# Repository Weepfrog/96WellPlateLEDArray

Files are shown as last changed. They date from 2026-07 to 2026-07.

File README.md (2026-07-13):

# 12×8 High-Power 660nm LED Array

A 96-LED (12 across × 8 down, 9 mm pitch) deep-red 660 nm panel with **per-LED
dimming** and **per-LED temperature sensing**, driven by an ESP32 DevKitC.
Designed for JLCPCB fabrication + assembly; all parts chosen from the
JLCPCB/LCSC library (stock verified 2026-07-13).

## System overview

```
24V 4-6A brick ──► CONTROL BOARD ══ 4× 50-way + 1× 20-way IDC ribbon ══► LED BOARD
                   96× PT4115 buck CC        192 anode/cathode lines        96× 660nm 3535 LED
                   6× PCA9685 PWM (I2C)      + analog/logic lines           96× 10k NTC
                   XL1509 5V rail                                           6× CD74HC4067 mux
                   ESP32 DevKitC socket                                     flat back → heatsink
                   3 buttons + status LEDs
```

- **~50 W** total at full drive (≈0.5 W per LED @ 256 mA, huge margin on 3 W-rated LEDs)
- Per-LED PWM: one PT4115 buck constant-current channel per LED, DIM pins on six
  PCA9685 16-channel I2C PWM expanders (run PWM at ~244 Hz → ~10-11 usable bits)
- Per-LED temperature: one 0603 NTC beside each LED, multiplexed 16:1 onto six
  ESP32 ADC1 inputs
- LED board is 4-layer with thermal-via farms; back face is bare copper for a
  bolt-on heatsink (use an insulating thermal pad)

## Repository layout

| Path | What |
|---|---|
| `12x8 Led Array 9mm pitch/` | **LED board** KiCad project (96 LEDs + NTCs + muxes) |
| `control-board/` | **Control board** KiCad project (drivers, PWM, ESP32, UI) |
| `libraries/` | `jlc_parts` symbol/footprint/3D library (converted from EasyEDA, JLCPCB-exact pads) |
| `scripts/design_data.py` | **Single source of truth**: every part, position, and net |
| `scripts/gen_schematics.py` | Regenerates both `.kicad_sch` (parts placed, you wire per CONNECTIONS.md) |
| `scripts/gen_pcbs.py` | Regenerates both `.kicad_pcb` (footprints pre-placed) |
| `reference/datasheets/` | Datasheets for key parts |
| `production/` | JLCPCB BOM + CPL exports |
| `CONNECTIONS.md` | **Your wiring guide** — every net, pin by pin |

## Workflow

1. **Schematics are hierarchical and fully wired**: each board is a root
   sheet + one sub-sheet (`well.kicad_sch` / `channel.kicad_sch`)
   instantiated 96×, with references matching `CONNECTIONS.md` (LED1-96,
   U1-96, …). Verified automatically: KiCad's exported netlist matches the
   intended netlist in `design_data.py` net-for-net; ERC is clean (3 benign
   library-mismatch warnings on the control board). Review, then move to
   layout.
2. Open the PCB — footprints are pre-placed (LED grid at exact 9.0 mm
   pitch; placement still draft). Run **Tools → Update PCB from Schematic
   (F8)**, then route.
3. Regenerating: `python scripts/gen_schematics_hier.py`, then
   `scripts/gen_pcbs.py` with KiCad's Python (see script headers), then
   `python scripts/gen_connections.py`. Verify with
   `scripts/verify_netlist.py` (see header). **Regeneration overwrites the
   sch/pcb files** — don't rerun after manual edits unless you want a reset.

## Key design rules (don't skip)

- **LED polarity:** pad 1 = anode (marked `+` on silk), pad 2 = cathode,
  pad 3 = center thermal pad — **tie pad 3 to pad 2 (cathode)** per Hongli's
  datasheet. Each LED's thermal island is at its own cathode potential, so the
  heatsink must be electrically isolated (thermal pad, not bare paste).
- **PT4115 DIM floats high** = full brightness. Every DIM has a 100k pulldown
  so the panel boots dark. Keep them.
- **One reflow only** for the LEDs (datasheet) — LED board is single-side
  assembly, which satisfies this. Don't hot-air rework casually.
- 24 V power enters each board via its own screw terminal — **do not route
  LED supply current through the IDC ribbons** (they carry per-channel
  anode/cathode pairs and logic only).
- IDC headers and ESP32 sockets are through-hole: hand-solder them (cheaper
  than JLCPCB THT assembly).

## Swapping LED wavelengths

The design is wavelength-agnostic on purpose:

- The 3535 3-pad footprint is the industry-standard pattern (Cree XP
  compatible). 730 nm far-red, 850/940 nm IR, blue, and UV parts from Hongli,
  Silverlight, JNJ and others drop straight in.
- The PT4115 buck **does not care about forward voltage** — anything from
  ~1.5 V (IR) to ~3.4 V (blue/UV) runs at the same regulated current with zero
  component changes.
- Current is set only by the 0.39 Ω sense resistor (256 mA). For a lower-rated
  LED, change R1–R96 on the control board: `I = 0.1 V / Rs`.
- Checklist when swapping: 3535 package with center pad, anode on pad 1 /
  matching polarity, continuous current rating ≥ 300 mA, note the part's own
  reflow limits.
- Mixed arrays are fine too (e.g. 660 nm + 730 nm checkerboard) since every
  channel is independent.

## Firmware map (ESP32 DevKitC-38)

| GPIO | Function |
|---|---|
| 21 / 22 | I2C SDA / SCL → PCA9685 ×6 (0x40–0x45), optional ADS1115 (0x48) |
| 16 / 17 / 18 / 19 | Mux address S0–S3 (shared, all six muxes) |
| 32, 33, 34, 35, 36, 39 | ADC1 inputs ← NTC_SIG1–6 (mux outputs) |
| 25 | Fan PWM (low-side AO3400A) |
| 4 / 13 | Status LED (blue) / Fault LED (red) |
| 14 / 27 / 26 | Buttons MODE / UP / DOWN (to GND, internal pull-ups) |

NTC conversion: 10k NTC (B=3434 K) high side, 10k 1% low side, ratiometric to
3.3 V. Scan all 96 via mux (settle ≥200 µs after address change). Derate any
channel whose pad temperature approaches 85 °C (Hongli's recommended limit).

## Safety

50 W of 660 nm in a 10 cm square is extremely bright — never look at the
array at power, ramp brightness in firmware, and treat the NTC thermal
shutdown as a backstop, not a substitute for the heatsink.

## Status

- [x] Architecture + parts selection (all JLCPCB-stocked, C-numbers in BOM)
- [x] Schematics generated, parts placed with library-verified pinouts
- [ ] PCBs with pre-placed footprints
- [ ] CONNECTIONS.md wiring guide
- [ ] JLCPCB BOM/CPL exports
- [ ] User wiring + routing
- [ ] Order + bring-up

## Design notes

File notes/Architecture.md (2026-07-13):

---
tags: [96-well-led-array, hardware]
---

# Architecture

```
24V 4-6A brick ─┬─► CONTROL BOARD (170×190mm, 2-layer)
                │     96× PT4115 buck CC channel (256mA, one per well)
                │     6× PCA9685 16-ch I2C PWM → per-well dimming
                │     XL1509-5.0 → 5V rail → ESP32 DevKitC (socketed)
                │     3 buttons + 3 status LEDs + fan switch
                │
                │  4× 50-way IDC ribbon (192 anode/cathode lines)
                │  1× 20-way IDC ribbon (6 analog + 4 addr + 3V3 + GND)
                │
                └─► LED BOARD (140×120mm, 4-layer, flat back → heatsink)
                      96× 660nm 3535 LED at exact 9.0mm SBS pitch
                      96× 10k NTC (one beside each LED)
                      6× CD74HC4067 16:1 mux
```

## Why this shape

- **Per-well dimming at 256 mA** rules out matrix scanning (can't sustain
  power) and display-driver ICs (≤90 mA). One tiny hysteretic buck per LED is
  the cheapest correct answer (~$0.19/channel). See [[Design Decisions]].
- The PT4115 floats its LED between the sense resistor and the inductor, so
  **each well needs its own anode AND cathode line** — hence 192 ribbon lines.
  Each channel's pair sits on adjacent IDC pins to minimize loop area.
- Drivers live on the control board so the LED board's back face is a flat,
  unbroken thermal surface and the NTC analog lines stay away from switching
  noise.
- 96 NTC signals reduce to 10 ribbon lines via the six on-board muxes.

## Channel numbering

`n = (row-1)*12 + col`, rows top→bottom 1-8, cols left→right 1-12, viewed
from the LED side. CH1 = A1 corner well, CH96 = H12. Same numbering on both
boards, in [[../CONNECTIONS|CONNECTIONS]], and in firmware.

## Thermal path

LED thermal pad (tied to its cathode) → 5-via farm → inner + back copper →
insulating thermal pad → heatsink. Per-well NTC lets firmware derate any hot
well; Hongli's limit is 85 °C at the cathode pad ([[Bring-Up Checklist]]).
Heatsink must be electrically isolated because the thermal islands carry
cathode potential.

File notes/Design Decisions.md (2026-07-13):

---
tags: [96-well-led-array, decisions]
---

# Design Decisions

Decisions confirmed 2026-07-13 (planning session): **~50 W** total power ·
**24 V** brick · **per-LED control** · **two boards**.

## Topology: one buck per LED

Considered and rejected:
- **Matrix scanning** — 1/8 duty needs 8× peak current; LEDs can't sustain it,
  and average power collapses.
- **Multichannel display drivers** (TLC59xx, MBI…) — top out at ~60-90 mA/ch;
  we need 256 mA.
- **String + shunt-switch (TPS92662 matrix manager)** — elegant but pricey,
  automotive parts thin at LCSC.
- **Linear per-channel from a low rail** — a 24 V→3 V/34 A converter plus 40 W
  of linear dissipation; awful.

**Chosen:** PT4115 hysteretic buck per channel from 24 V. Confirmed by
datasheet math: single 2.1 V LED from 24 V → ~9 % duty, fsw ≈ 630 kHz with
47 µH — inside the 1 MHz limit, no minimum-on-time problem.

## LED: Hongli HL-C3535F15R3GA-ZW (C5445086)

- No 660 nm LED exists in JLCPCB's *Basic* library; nothing viable ≥0.5 W in
  2835/3030 was in stock → 3535 it is.
- 3 W-rated part run at 0.5 W → big lifetime/thermal margin.
- Pad 1 = anode (`+` silk), pad 2 = cathode, pad 3 = thermal → **tie pad 3 to
  pad 2** per datasheet recommendation (safe whether or not the pad is
  internally bonded to the cathode).
- **One reflow only** — LED board is single-side assembly. Avoid hot-air rework.

## LED swapability

Requirement: swap wavelengths without redesign.
- 3535 3-pad is the industry-standard (XP-style) footprint: 730 nm far-red,
  850/940 nm IR, blue, UV drop in.
- PT4115 buck is Vf-agnostic (~1.5–3.4 V all fine) — zero component changes.
- Current set only by Rs: `I = 0.1 V / 0.39 Ω = 256 mA`; change R1-R96 on the
  control board for lower-rated LEDs.
- Mixed-wavelength (e.g. 660/730 checkerboard) works since channels are
  independent.

## Dimming: PCA9685 at ~244 Hz

PCA9685's 12-bit PWM at max 1526 Hz has 160 ns LSBs — far below the PT4115
DIM response (~tens of µs). At 244 Hz prescale, 1 LSB ≈ 1 µs → **~10-11 usable
bits**, monotonic. Full-panel update over 400 kHz I2C ≈ 90 Hz.
PCA9685 is NXP-only at LCSC (~$2, the priciest BOM line); AW9523B is the
8-bit fallback if it goes out of stock.

## Temperature sensing

10k NTC (B=3434) + 10k 1% divider from 3.3 V, ratiometric into the ESP32 ADC
(nonlinearity mostly cancels; absolute accuracy ±2 °C is plenty for derating).
Six CD74HC4067 on the LED board; ADS1115 footprint on the control board is
DNP insurance if the internal ADC disappoints.

## Boot safety

PT4115 DIM **floating = 100 % on**. Defenses: PCA9685 outputs are LOW at
reset, /OE hard-tied to GND, and a 100k pulldown on every DIM line. The panel
cannot boot bright.

## Interconnect

2.54 mm shrouded IDC (2.5-3 A/pin vs 256 mA needed), keyed against reversal.
24 V never crosses the ribbons — it enters only at the control board screw
terminal/barrel jack. Ribbon spare pins carry GND.

## Related

[[Architecture]] · [[Parts and BOM]] · [[../CONNECTIONS|CONNECTIONS]]

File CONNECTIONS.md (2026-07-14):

# CONNECTIONS.md — complete wiring reference

Generated from `scripts/design_data.py`. The hierarchical schematics are **already wired to match this document** (verified: KiCad's exported netlist matches every net below exactly, ERC clean). Use this as the review checklist and as the reference during PCB routing, firmware bring-up, and debugging.

**Channel numbering:** `n = (row-1)*12 + col`, rows top→bottom 1-8, columns left→right 1-12 looking at the LED side. CH1 = top-left well, CH96 = bottom-right.

## ESP32 DevKitC-38 socket map (control board J10/J11)

J10 = left socket row, J11 = right socket row, **pin 1 of both = the 3V3/GND end** (opposite the USB connector).

| J10 pin | DevKit pin | Connect to | | J11 pin | DevKit pin | Connect to |
|---|---|---|---|---|---|---|
| 1 | 3V3 | +3.3V | | 1 | GND | GND |
| 2 | EN | — | | 2 | GPIO23 | — |
| 3 | GPIO36/VP | NTC_SIG5 | | 3 | GPIO22 | I2C_SCL |
| 4 | GPIO39/VN | NTC_SIG6 | | 4 | GPIO1/TX0 | — |
| 5 | GPIO34 | NTC_SIG3 | | 5 | GPIO3/RX0 | — |
| 6 | GPIO35 | NTC_SIG4 | | 6 | GPIO21 | I2C_SDA |
| 7 | GPIO32 | NTC_SIG1 | | 7 | GND | GND |
| 8 | GPIO33 | NTC_SIG2 | | 8 | GPIO19 | MUX_A3 |
| 9 | GPIO25 | FAN_PWM | | 9 | GPIO18 | MUX_A2 |
| 10 | GPIO26 | BTN_DOWN | | 10 | GPIO5 | — |
| 11 | GPIO27 | BTN_UP | | 11 | GPIO17 | MUX_A1 |
| 12 | GPIO14 | BTN_MODE | | 12 | GPIO16 | MUX_A0 |
| 13 | GPIO12 | — | | 13 | GPIO4 | LED_STATUS |
| 14 | GND | GND | | 14 | GPIO0 | — |
| 15 | GPIO13 | LED_FAULT | | 15 | GPIO2 | — |
| 16 | GPIO9/D2 | — | | 16 | GPIO15 | — |
| 17 | GPIO10/D3 | — | | 17 | GPIO8/D1 | — |
| 18 | GPIO11/CMD | — | | 18 | GPIO7/D0 | — |
| 19 | 5V | +5V | | 19 | GPIO6/CLK | — |

GPIO summary: **GPIO21** = I2C SDA (PCA9685 x6, ADS1115 opt.); **GPIO22** = I2C SCL; **GPIO16** = MUX_A0; **GPIO17** = MUX_A1; **GPIO18** = MUX_A2; **GPIO19** = MUX_A3; **GPIO32** = NTC_SIG1 (ADC1_CH4); **GPIO33** = NTC_SIG2 (ADC1_CH5); **GPIO34** = NTC_SIG3 (ADC1_CH6); **GPIO35** = NTC_SIG4 (ADC1_CH7); **GPIO36/VP** = NTC_SIG5 (ADC1_CH0); **GPIO39/VN** = NTC_SIG6 (ADC1_CH3); **GPIO25** = FAN_PWM (Q1 gate via R201); **GPIO4** = STATUS LED2 (blue); **GPIO13** = FAULT LED3 (red); **GPIO14** = SW1 MODE (to GND, internal pull-up); **GPIO27** = SW2 UP (to GND, internal pull-up); **GPIO26** = SW3 DOWN (to GND, internal pull-up)

## Logical channel map (well ↔ channel ↔ driver ↔ PWM)

The driver serving a well is **not** the same index — each board's ribbon pinout was optimized independently to minimize crossings, and the cable wires them together slot-for-slot. Firmware addresses a well's brightness through the PCA output in this table, and reads its temperature through the mux input. **This is the mapping to hard-code.**

| CH | Well (grid) | Ribbon | Driver | PWM (PCA.out) | NTC (mux.in) |
|---|---|---|---|---|---|
| 1 | LED37 (r4c1) | J1 p1/2 | U10 | U105.LED2 | U3.I5 |
| 2 | LED38 (r4c2) | J1 p3/4 | U11 | U105.LED1 | U3.I10 |
| 3 | LED39 (r4c3) | J1 p5/6 | U12 | U105.LED0 | U3.I4 |
| 4 | LED40 (r4c4) | J1 p7/8 | U21 | U105.LED6 | U3.I11 |
| 5 | LED25 (r3c1) | J1 p9/10 | U22 | U105.LED5 | U2.I3 |
| 6 | LED41 (r4c5) | J1 p11/12 | U23 | U105.LED4 | U3.I3 |
| 7 | LED26 (r3c2) | J1 p13/14 | U24 | U105.LED3 | U2.I12 |
| 8 | LED27 (r3c3) | J1 p15/16 | U33 | U105.LED10 | U2.I2 |
| 9 | LED13 (r2c1) | J1 p17/18 | U34 | U105.LED9 | U1.I1 |
| 10 | LED42 (r4c6) | J1 p21/22 | U35 | U105.LED8 | U3.I12 |
| 11 | LED28 (r3c4) | J1 p23/24 | U36 | U105.LED7 | U2.I13 |
| 12 | LED14 (r2c2) | J1 p25/26 | U44 | U105.LED15 | U1.I14 |
| 13 | LED15 (r2c3) | J1 p27/28 | U45 | U105.LED14 | U1.I0 |
| 14 | LED1 (r1c1) | J1 p29/30 | U46 | U105.LED13 | U1.I7 |
| 15 | LED29 (r3c5) | J1 p31/32 | U47 | U105.LED12 | U2.I1 |
| 16 | LED2 (r1c2) | J1 p33/34 | U48 | U105.LED11 | U1.I8 |
| 17 | LED16 (r2c4) | J2 p1/2 | U5 | U104.LED4 | U1.I15 |
| 18 | LED3 (r1c3) | J2 p3/4 | U6 | U104.LED3 | U1.I6 |
| 19 | LED43 (r4c7) | J2 p5/6 | U17 | U104.LED8 | U3.I2 |
| 20 | LED17 (r2c5) | J2 p7/8 | U7 | U104.LED2 | U2.I7 |
| 21 | LED4 (r1c4) | J2 p9/10 | U18 | U104.LED7 | U1.I9 |
| 22 | LED30 (r3c6) | J2 p11/12 | U29 | U104.LED12 | U2.I14 |
| 23 | LED31 (r3c7) | J2 p13/14 | U41 | U104.LED15 | U2.I0 |
| 24 | LED18 (r2c6) | J2 p15/16 | U30 | U104.LED11 | U2.I8 |
| 25 | LED5 (r1c5) | J2 p17/18 | U19 | U104.LED6 | U1.I5 |
| 26 | LED44 (r4c8) | J2 p21/22 | U8 | U104.LED1 | U3.I13 |
| 27 | LED32 (r3c8) | J2 p23/24 | U42 | U104.LED14 | U2.I15 |
| 28 | LED6 (r1c6) | J2 p25/26 | U9 | U104.LED0 | U1.I10 |
| 29 | LED19 (r2c7) | J2 p27/28 | U31 | U104.LED10 | U2.I6 |
| 30 | LED45 (r4c9) | J2 p29/30 | U20 | U104.LED5 | U3.I1 |
| 31 | LED7 (r1c7) | J2 p31/32 | U43 | U104.LED13 | U1.I4 |
| 32 | LED20 (r2c8) | J2 p33/34 | U32 | U104.LED9 | U2.I9 |
| 33 | LED8 (r1c8) | J3 p1/2 | U1 | U101.LED3 | U1.I11 |
| 34 | LED33 (r3c9) | J3 p3/4 | U13 | U101.LED7 | U3.I7 |
| 35 | LED21 (r2c9) | J3 p5/6 | U2 | U101.LED2 | U2.I5 |
| 36 | LED9 (r1c9) | J3 p7/8 | U25 | U101.LED11 | U1.I3 |
| 37 | LED46 (r4c10) | J3 p9/10 | U14 | U101.LED6 | U3.I14 |
| 38 | LED34 (r3c10) | J3 p11/12 | U37 | U101.LED15 | U3.I8 |
| 39 | LED22 (r2c10) | J3 p13/14 | U26 | U101.LED10 | U2.I10 |
| 40 | LED10 (r1c10) | J3 p15/16 | U38 | U101.LED14 | U1.I12 |
| 41 | LED47 (r4c11) | J3 p17/18 | U3 | U101.LED1 | U3.I0 |
| 42 | LED35 (r3c11) | J3 p21/22 | U15 | U101.LED5 | U3.I6 |
| 43 | LED23 (r2c11) | J3 p23/24 | U27 | U101.LED9 | U2.I4 |
| 44 | LED11 (r1c11) | J3 p25/26 | U4 | U101.LED0 | U1.I2 |
| 45 | LED48 (r4c12) | J3 p27/28 | U16 | U101.LED4 | U3.I15 |
| 46 | LED36 (r3c12) | J3 p29/30 | U39 | U101.LED13 | U3.I9 |
| 47 | LED24 (r2c12) | J3 p31/32 | U28 | U101.LED8 | U2.I11 |
| 48 | LED12 (r1c12) | J3 p33/34 | U40 | U101.LED12 | U1.I13 |
| 49 | LED65 (r6c5) | J4 p1/2 | U57 | U106.LED3 | U5.I7 |
| 50 | LED86 (r8c2) | J4 p3/4 | U59 | U106.LED1 | U6.I10 |
| 51 | LED75 (r7c3) | J4 p5/6 | U60 | U106.LED0 | U5.I2 |
| 52 | LED85 (r8c1) | J4 p7/8 | U58 | U106.LED2 | U6.I5 |
| 53 | LED54 (r5c6) | J4 p9/10 | U56 | U106.LED4 | U4.I10 |
| 54 | LED64 (r6c4) | J4 p11/12 | U70 | U106.LED7 | U4.I15 |
| 55 | LED74 (r7c2) | J4 p13/14 | U72 | U106.LED5 | U5.I12 |
| 56 | LED53 (r5c5) | J4 p15/16 | U71 | U106.LED6 | U4.I5 |
| 57 | LED73 (r7c1) | J4 p17/18 | U69 | U106.LED8 | U5.I3 |
| 58 | LED63 (r6c3) | J4 p21/22 | U81 | U106.LED12 | U4.I0 |
| 59 | LED62 (r6c2) | J4 p23/24 | U84 | U106.LED9 | U4.I14 |
| 60 | LED52 (r5c4) | J4 p25/26 | U83 | U106.LED10 | U4.I9 |
| 61 | LED61 (r6c1) | J4 p27/28 | U82 | U106.LED11 | U4.I1 |
| 62 | LED51 (r5c3) | J4 p29/30 | U94 | U106.LED15 | U4.I6 |
| 63 | LED50 (r5c2) | J4 p31/32 | U95 | U106.LED14 | U4.I8 |
| 64 | LED49 (r5c1) | J4 p33/34 | U96 | U106.LED13 | U4.I7 |
| 65 | LED87 (r8c3) | J5 p1/2 | U89 | U103.LED15 | U6.I4 |
| 66 | LED76 (r7c4) | J5 p3/4 | U90 | U103.LED14 | U5.I13 |
| 67 | LED55 (r5c7) | J5 p5/6 | U77 | U103.LED10 | U4.I4 |
| 68 | LED88 (r8c4) | J5 p7/8 | U91 | U103.LED13 | U6.I11 |
| 69 | LED66 (r6c6) | J5 p9/10 | U78 | U103.LED9 | U5.I8 |
| 70 | LED77 (r7c5) | J5 p11/12 | U65 | U103.LED6 | U5.I1 |
| 71 | LED56 (r5c8) | J5 p13/14 | U53 | U103.LED2 | U4.I11 |
| 72 | LED78 (r7c6) | J5 p15/16 | U66 | U103.LED5 | U5.I14 |
| 73 | LED89 (r8c5) | J5 p17/18 | U92 | U103.LED12 | U6.I3 |
| 74 | LED67 (r6c7) | J5 p21/22 | U79 | U103.LED8 | U5.I6 |
| 75 | LED90 (r8c6) | J5 p23/24 | U54 | U103.LED1 | U6.I12 |
| 76 | LED79 (r7c7) | J5 p25/26 | U80 | U103.LED7 | U5.I0 |
| 77 | LED68 (r6c8) | J5 p27/28 | U93 | U103.LED11 | U5.I9 |
| 78 | LED57 (r5c9) | J5 p29/30 | U67 | U103.LED4 | U4.I3 |
| 79 | LED91 (r8c7) | J5 p31/32 | U55 | U103.LED0 | U6.I2 |
| 80 | LED80 (r7c8) | J5 p33/34 | U68 | U103.LED3 | U5.I15 |
| 81 | LED92 (r8c8) | J6 p1/2 | U85 | U102.LED15 | U6.I13 |
| 82 | LED69 (r6c9) | J6 p3/4 | U73 | U102.LED11 | U5.I5 |
| 83 | LED81 (r7c9) | J6 p5/6 | U86 | U102.LED14 | U6.I7 |
| 84 | LED93 (r8c9) | J6 p7/8 | U61 | U102.LED7 | U6.I1 |
| 85 | LED58 (r5c10) | J6 p9/10 | U74 | U102.LED10 | U4.I12 |
| 86 | LED70 (r6c10) | J6 p11/12 | U49 | U102.LED3 | U5.I10 |
| 87 | LED82 (r7c10) | J6 p13/14 | U62 | U102.LED6 | U6.I8 |
| 88 | LED94 (r8c10) | J6 p15/16 | U87 | U102.LED13 | U6.I14 |
| 89 | LED59 (r5c11) | J6 p17/18 | U50 | U102.LED2 | U4.I2 |
| 90 | LED71 (r6c11) | J6 p21/22 | U75 | U102.LED9 | U5.I4 |
| 91 | LED83 (r7c11) | J6 p23/24 | U88 | U102.LED12 | U6.I6 |
| 92 | LED95 (r8c11) | J6 p25/26 | U63 | U102.LED5 | U6.I0 |
| 93 | LED60 (r5c12) | J6 p27/28 | U51 | U102.LED1 | U4.I13 |
| 94 | LED72 (r6c12) | J6 p29/30 | U76 | U102.LED8 | U5.I11 |
| 95 | LED84 (r7c12) | J6 p31/32 | U64 | U102.LED4 | U6.I9 |
| 96 | LED96 (r8c12) | J6 p33/34 | U52 | U102.LED0 | U6.I15 |

## Control board — driver channel (repeat for n = 1…96)

```
+24V ──┬── R<n>.1   R<n> = 0.39Ω sense
       │   R<n>.2 ──●── U<n>.4 (CSN) ── LED_A<n> ── ribbon pin (see table)
       ├── C<n>.1   (2.2µF 50V; C<n>.2 → GND)
       ├── D<n>.1   (SS34 cathode/band side!)
       └── U<n>.5 (VIN)
U<n>.1 (SW) ──●── L<n>.1        L<n> = 47µH
              └── D<n>.2 (SS34 anode)
L<n>.2 ── LED_K<n> ── ribbon pin (see table)
U<n>.3 (DIM) ──●── R<10x>.1 (100k pulldown; .2 → GND)
               └── PCA9685 output (see table)
U<n>.2 (GND) → GND
```

Drivers are indexed physically (U1…U96); the logical channel each carries is CH = whichever ribbon slot it was assigned. Table sorted by driver.

| Driver | CH | Rs | L | D | Cin | pulldown | ribbon A / K | DIM source |
|---|---|---|---|---|---|---|---|---|
| U1 | 33 | R1 | L1 | D1 | C1 | R101 | J3.1 / J3.2 | U101.9 (LED3) |
| U2 | 35 | R2 | L2 | D2 | C2 | R102 | J3.5 / J3.6 | U101.8 (LED2) |
| U3 | 41 | R3 | L3 | D3 | C3 | R103 | J3.17 / J3.18 | U101.7 (LED1) |
| U4 | 44 | R4 | L4 | D4 | C4 | R104 | J3.25 / J3.26 | U101.6 (LED0) |
| U5 | 17 | R5 | L5 | D5 | C5 | R105 | J2.1 / J2.2 | U104.10 (LED4) |
| U6 | 18 | R6 | L6 | D6 | C6 | R106 | J2.3 / J2.4 | U104.9 (LED3) |
| U7 | 20 | R7 | L7 | D7 | C7 | R107 | J2.7 / J2.8 | U104.8 (LED2) |
| U8 | 26 | R8 | L8 | D8 | C8 | R108 | J2.21 / J2.22 | U104.7 (LED1) |
| U9 | 28 | R9 | L9 | D9 | C9 | R109 | J2.25 / J2.26 | U104.6 (LED0) |
| U10 | 1 | R10 | L10 | D10 | C10 | R110 | J1.1 / J1.2 | U105.8 (LED2) |
| U11 | 2 | R11 | L11 | D11 | C11 | R111 | J1.3 / J1.4 | U105.7 (LED1) |
| U12 | 3 | R12 | L12 | D12 | C12 | R112 | J1.5 / J1.6 | U105.6 (LED0) |
| U13 | 34 | R13 | L13 | D13 | C13 | R113 | J3.3 / J3.4 | U101.13 (LED7) |
| U14 | 37 | R14 | L14 | D14 | C14 | R114 | J3.9 / J3.10 | U101.12 (LED6) |
| U15 | 42 | R15 | L15 | D15 | C15 | R115 | J3.21 / J3.22 | U101.11 (LED5) |
| U16 | 45 | R16 | L16 | D16 | C16 | R116 | J3.27 / J3.28 | U101.10 (LED4) |
| U17 | 19 | R17 | L17 | D17 | C17 | R117 | J2.5 / J2.6 | U104.15 (LED8) |
| U18 | 21 | R18 | L18 | D18 | C18 | R118 | J2.9 / J2.10 | U104.13 (LED7) |
| U19 | 25 | R19 | L19 | D19 | C19 | R119 | J2.17 / J2.18 | U104.12 (LED6) |
| U20 | 30 | R20 | L20 | D20 | C20 | R120 | J2.29 / J2.30 | U104.11 (LED5) |
| U21 | 4 | R21 | L21 | D21 | C21 | R121 | J1.7 / J1.8 | U105.12 (LED6) |
| U22 | 5 | R22 | L22 | D22 | C22 | R122 | J1.9 / J1.10 | U105.11 (LED5) |
| U23 | 6 | R23 | L23 | D23 | C23 | R123 | J1.11 / J1.12 | U105.10 (LED4) |
| U24 | 7 | R24 | L24 | D24 | C24 | R124 | J1.13 / J1.14 | U105.9 (LED3) |
| U25 | 36 | R25 | L25 | D25 | C25 | R125 | J3.7 / J3.8 | U101.18 (LED11) |
| U26 | 39 | R26 | L26 | D26 | C26 | R126 | J3.13 / J3.14 | U101.17 (LED10) |
| U27 | 43 | R27 | L27 | D27 | C27 | R127 | J3.23 / J3.24 | U101.16 (LED9) |
| U28 | 47 | R28 | L28 | D28 | C28 | R128 | J3.31 / J3.32 | U101.15 (LED8) |
| U29 | 22 | R29 | L29 | D29 | C29 | R129 | J2.11 / J2.12 | U104.19 (LED12) |
| U30 | 24 | R30 | L30 | D30 | C30 | R130 | J2.15 / J2.16 | U104.18 (LED11) |
| U31 | 29 | R31 | L31 | D31 | C31 | R131 | J2.27 / J2.28 | U104.17 (LED10) |
| U32 | 32 | R32 | L32 | D32 | C32 | R132 | J2.33 / J2.34 | U104.16 (LED9) |
| U33 | 8 | R33 | L33 | D33 | C33 | R133 | J1.15 / J1.16 | U105.17 (LED10) |
| U34 | 9 | R34 | L34 | D34 | C34 | R134 | J1.17 / J1.18 | U105.16 (LED9) |
| U35 | 10 | R35 | L35 | D35 | C35 | R135 | J1.21 / J1.22 | U105.15 (LED8) |
| U36 | 11 | R36 | L36 | D36 | C36 | R136 | J1.23 / J1.24 | U105.13 (LED7) |
| U37 | 38 | R37 | L37 | D37 | C37 | R137 | J3.11 / J3.12 | U101.22 (LED15) |
| U38 | 40 | R38 | L38 | D38 | C38 | R138 | J3.15 / J3.16 | U101.21 (LED14) |
| U39 | 46 | R39 | L39 | D39 | C39 | R139 | J3.29 / J3.30 | U101.20 (LED13) |
| U40 | 48 | R40 | L40 | D40 | C40 | R140 | J3.33 / J3.34 | U101.19 (LED12) |
| U41 | 23 | R41 | L41 | D41 | C41 | R141 | J2.13 / J2.14 | U104.22 (LED15) |
| U42 | 27 | R42 | L42 | D42 | C42 | R142 | J2.23 / J2.24 | U104.21 (LED14) |
| U43 | 31 | R43 | L43 | D43 | C43 | R143 | J2.31 / J2.32 | U104.20 (LED13) |
| U44 | 12 | R44 | L44 | D44 | C44 | R144 | J1.25 / J1.26 | U105.22 (LED15) |
| U45 | 13 | R45 | L45 | D45 | C45 | R145 | J1.27 / J1.28 | U105.21 (LED14) |
| U46 | 14 | R46 | L46 | D46 | C46 | R146 | J1.29 / J1.30 | U105.20 (LED13) |
| U47 | 15 | R47 | L47 | D47 | C47 | R147 | J1.31 / J1.32 | U105.19 (LED12) |
| U48 | 16 | R48 | L48 | D48 | C48 | R148 | J1.33 / J1.34 | U105.18 (LED11) |
| U49 | 86 | R49 | L49 | D49 | C49 | R149 | J6.11 / J6.12 | U102.9 (LED3) |
| U50 | 89 | R50 | L50 | D50 | C50 | R150 | J6.17 / J6.18 | U102.8 (LED2) |
| U51 | 93 | R51 | L51 | D51 | C51 | R151 | J6.27 / J6.28 | U102.7 (LED1) |
| U52 | 96 | R52 | L52 | D52 | C52 | R152 | J6.33 / J6.34 | U102.6 (LED0) |
| U53 | 71 | R53 | L53 | D53 | C53 | R153 | J5.13 / J5.14 | U103.8 (LED2) |
| U54 | 75 | R54 | L54 | D54 | C54 | R154 | J5.23 / J5.24 | U103.7 (LED1) |
| U55 | 79 | R55 | L55 | D55 | C55 | R155 | J5.31 / J5.32 | U103.6 (LED0) |
| U56 | 53 | R56 | L56 | D56 | C56 | R156 | J4.9 / J4.10 | U106.10 (LED4) |
| U57 | 49 | R57 | L57 | D57 | C57 | R157 | J4.1 / J4.2 | U106.9 (LED3) |
| U58 | 52 | R58 | L58 | D58 | C58 | R158 | J4.7 / J4.8 | U106.8 (LED2) |
| U59 | 50 | R59 | L59 | D59 | C59 | R159 | J4.3 / J4.4 | U106.7 (LED1) |
| U60 | 51 | R60 | L60 | D60 | C60 | R160 | J4.5 / J4.6 | U106.6 (LED0) |
| U61 | 84 | R61 | L61 | D61 | C61 | R161 | J6.7 / J6.8 | U102.13 (LED7) |
| U62 | 87 | R62 | L62 | D62 | C62 | R162 | J6.13 / J6.14 | U102.12 (LED6) |
| U63 | 92 | R63 | L63 | D63 | C63 | R163 | J6.25 / J6.26 | U102.11 (LED5) |
| U64 | 95 | R64 | L64 | D64 | C64 | R164 | J6.31 / J6.32 | U102.10 (LED4) |
| U65 | 70 | R65 | L65 | D65 | C65 | R165 | J5.11 / J5.12 | U103.12 (LED6) |
| U66 | 72 | R66 | L66 | D66 | C66 | R166 | J5.15 / J5.16 | U103.11 (LED5) |
| U67 | 78 | R67 | L67 | D67 | C67 | R167 | J5.29 / J5.30 | U103.10 (LED4) |
| U68 | 80 | R68 | L68 | D68 | C68 | R168 | J5.33 / J5.34 | U103.9 (LED3) |
| U69 | 57 | R69 | L69 | D69 | C69 | R169 | J4.17 / J4.18 | U106.15 (LED8) |
| U70 | 54 | R70 | L70 | D70 | C70 | R170 | J4.11 / J4.12 | U106.13 (LED7) |
| U71 | 56 | R71 | L71 | D71 | C71 | R171 | J4.15 / J4.16 | U106.12 (LED6) |
| U72 | 55 | R72 | L72 | D72 | C72 | R172 | J4.13 / J4.14 | U106.11 (LED5) |
| U73 | 82 | R73 | L73 | D73 | C73 | R173 | J6.3 / J6.4 | U102.18 (LED11) |
| U74 | 85 | R74 | L74 | D74 | C74 | R174 | J6.9 / J6.10 | U102.17 (LED10) |
| U75 | 90 | R75 | L75 | D75 | C75 | R175 | J6.21 / J6.22 | U102.16 (LED9) |
| U76 | 94 | R76 | L76 | D76 | C76 | R176 | J6.29 / J6.30 | U102.15 (LED8) |
| U77 | 67 | R77 | L77 | D77 | C77 | R177 | J5.5 / J5.6 | U103.17 (LED10) |
| U78 | 69 | R78 | L78 | D78 | C78 | R178 | J5.9 / J5.10 | U103.16 (LED9) |
| U79 | 74 | R79 | L79 | D79 | C79 | R179 | J5.21 / J5.22 | U103.15 (LED8) |
| U80 | 76 | R80 | L80 | D80 | C80 | R180 | J5.25 / J5.26 | U103.13 (LED7) |
| U81 | 58 | R81 | L81 | D81 | C81 | R181 | J4.21 / J4.22 | U106.19 (LED12) |
| U82 | 61 | R82 | L82 | D82 | C82 | R182 | J4.27 / J4.28 | U106.18 (LED11) |
| U83 | 60 | R83 | L83 | D83 | C83 | R183 | J4.25 / J4.26 | U106.17 (LED10) |
| U84 | 59 | R84 | L84 | D84 | C84 | R184 | J4.23 / J4.24 | U106.16 (LED9) |
| U85 | 81 | R85 | L85 | D85 | C85 | R185 | J6.1 / J6.2 | U102.22 (LED15) |
| U86 | 83 | R86 | L86 | D86 | C86 | R186 | J6.5 / J6.6 | U102.21 (LED14) |
| U87 | 88 | R87 | L87 | D87 | C87 | R187 | J6.15 / J6.16 | U102.20 (LED13) |
| U88 | 91 | R88 | L88 | D88 | C88 | R188 | J6.23 / J6.24 | U102.19 (LED12) |
| U89 | 65 | R89 | L89 | D89 | C89 | R189 | J5.1 / J5.2 | U103.22 (LED15) |
| U90 | 66 | R90 | L90 | D90 | C90 | R190 | J5.3 / J5.4 | U103.21 (LED14) |
| U91 | 68 | R91 | L91 | D91 | C91 | R191 | J5.7 / J5.8 | U103.20 (LED13) |
| U92 | 73 | R92 | L92 | D92 | C92 | R192 | J5.17 / J5.18 | U103.19 (LED12) |
| U93 | 77 | R93 | L93 | D93 | C93 | R193 | J5.27 / J5.28 | U103.18 (LED11) |
| U94 | 62 | R94 | L94 | D94 | C94 | R194 | J4.29 / J4.30 | U106.22 (LED15) |
| U95 | 63 | R95 | L95 | D95 | C95 | R195 | J4.31 / J4.32 | U106.21 (LED14) |
| U96 | 64 | R96 | L96 | D96 | C96 | R196 | J4.33 / J4.34 | U106.20 (LED13) |

## PCA9685 bank (control board)

All six: pin 28 (VDD) → +3.3V with 100nF (C121-C126), pin 14 (VSS) → GND, pin 23 (/OE) → GND, pin 25 (EXTCLK) → GND, pin 27 (SDA) → I2C_SDA, pin 26 (SCL) → I2C_SCL.
I2C_SDA/I2C_SCL → ESP32 GPIO21/GPIO22 + 4.7k pullups R210/R211 to +3.3V.

Address straps (pin → rail):

| Chip | Addr | A0(1) | A1(2) | A2(3) | A3(4) | A4(5) | A5(24) |
|---|---|---|---|---|---|---|---|
| U101 | 0x40 | GND | GND | GND | GND | GND | GND |
| U102 | 0x41 | +3.3V | GND | GND | GND | GND | GND |
| U103 | 0x42 | GND | +3.3V | GND | GND | GND | GND |
| U104 | 0x43 | +3.3V | +3.3V | GND | GND | GND | GND |
| U105 | 0x44 | GND | GND | +3.3V | GND | GND | GND |
| U106 | 0x45 | +3.3V | GND | +3.3V | GND | GND | GND |

## 5V rail (control board)

- **+24V**: R1.1, C1.1, D1.1 (K), U1.5 (VIN), R2.1, C2.1, D2.1 (K), U2.5 (VIN), R3.1, C3.1, D3.1 (K), U3.5 (VIN), R4.1, C4.1, D4.1 (K), U4.5 (VIN), R5.1, C5.1, D5.1 (K), U5.5 (VIN), R6.1, C6.1, D6.1 (K), U6.5 (VIN), R7.1, C7.1, D7.1 (K), U7.5 (VIN), R8.1, C8.1, D8.1 (K), U8.5 (VIN), R9.1, C9.1, D9.1 (K), U9.5 (VIN), R10.1, C10.1, D10.1 (K), U10.5 (VIN), R11.1, C11.1, D11.1 (K), U11.5 (VIN), R12.1, C12.1, D12.1 (K), U12.5 (VIN), R13.1, C13.1, D13.1 (K), U13.5 (VIN), R14.1, C14.1, D14.1 (K), U14.5 (VIN), R15.1, C15.1, D15.1 (K), U15.5 (VIN), R16.1, C16.1, D16.1 (K), U16.5 (VIN), R17.1, C17.1, D17.1 (K), U17.5 (VIN), R18.1, C18.1, D18.1 (K), U18.5 (VIN), R19.1, C19.1, D19.1 (K), U19.5 (VIN), R20.1, C20.1, D20.1 (K), U20.5 (VIN), R21.1, C21.1, D21.1 (K), U21.5 (VIN), R22.1, C22.1, D22.1 (K), U22.5 (VIN), R23.1, C23.1, D23.1 (K), U23.5 (VIN), R24.1, C24.1, D24.1 (K), U24.5 (VIN), R25.1, C25.1, D25.1 (K), U25.5 (VIN), R26.1, C26.1, D26.1 (K), U26.5 (VIN), R27.1, C27.1, D27.1 (K), U27.5 (VIN), R28.1, C28.1, D28.1 (K), U28.5 (VIN), R29.1, C29.1, D29.1 (K), U29.5 (VIN), R30.1, C30.1, D30.1 (K), U30.5 (VIN), R31.1, C31.1, D31.1 (K), U31.5 (VIN), R32.1, C32.1, D32.1 (K), U32.5 (VIN), R33.1, C33.1, D33.1 (K), U33.5 (VIN), R34.1, C34.1, D34.1 (K), U34.5 (VIN), R35.1, C35.1, D35.1 (K), U35.5 (VIN), R36.1, C36.1, D36.1 (K), U36.5 (VIN), R37.1, C37.1, D37.1 (K), U37.5 (VIN), R38.1, C38.1, D38.1 (K), U38.5 (VIN), R39.1, C39.1, D39.1 (K), U39.5 (VIN), R40.1, C40.1, D40.1 (K), U40.5 (VIN), R41.1, C41.1, D41.1 (K), U41.5 (VIN), R42.1, C42.1, D42.1 (K), U42.5 (VIN), R43.1, C43.1, D43.1 (K), U43.5 (VIN), R44.1, C44.1, D44.1 (K), U44.5 (VIN), R45.1, C45.1, D45.1 (K), U45.5 (VIN), R46.1, C46.1, D46.1 (K), U46.5 (VIN), R47.1, C47.1, D47.1 (K), U47.5 (VIN), R48.1, C48.1, D48.1 (K), U48.5 (VIN), R49.1, C49.1, D49.1 (K), U49.5 (VIN), R50.1, C50.1, D50.1 (K), U50.5 (VIN), R51.1, C51.1, D51.1 (K), U51.5 (VIN), R52.1, C52.1, D52.1 (K), U52.5 (VIN), R53.1, C53.1, D53.1 (K), U53.5 (VIN), R54.1, C54.1, D54.1 (K), U54.5 (VIN), R55.1, C55.1, D55.1 (K), U55.5 (VIN), R56.1, C56.1, D56.1 (K), U56.5 (VIN), R57.1, C57.1, D57.1 (K), U57.5 (VIN), R58.1, C58.1, D58.1 (K), U58.5 (VIN), R59.1, C59.1, D59.1 (K), U59.5 (VIN), R60.1, C60.1, D60.1 (K), U60.5 (VIN), R61.1, C61.1, D61.1 (K), U61.5 (VIN), R62.1, C62.1, D62.1 (K), U62.5 (VIN), R63.1, C63.1, D63.1 (K), U63.5 (VIN), R64.1, C64.1, D64.1 (K), U64.5 (VIN), R65.1, C65.1, D65.1 (K), U65.5 (VIN), R66.1, C66.1, D66.1 (K), U66.5 (VIN), R67.1, C67.1, D67.1 (K), U67.5 (VIN), R68.1, C68.1, D68.1 (K), U68.5 (VIN), R69.1, C69.1, D69.1 (K), U69.5 (VIN), R70.1, C70.1, D70.1 (K), U70.5 (VIN), R71.1, C71.1, D71.1 (K), U71.5 (VIN), R72.1, C72.1, D72.1 (K), U72.5 (VIN), R73.1, C73.1, D73.1 (K), U73.5 (VIN), R74.1, C74.1, D74.1 (K), U74.5 (VIN), R75.1, C75.1, D75.1 (K), U75.5 (VIN), R76.1, C76.1, D76.1 (K), U76.5 (VIN), R77.1, C77.1, D77.1 (K), U77.5 (VIN), R78.1, C78.1, D78.1 (K), U78.5 (VIN), R79.1, C79.1, D79.1 (K), U79.5 (VIN), R80.1, C80.1, D80.1 (K), U80.5 (VIN), R81.1, C81.1, D81.1 (K), U81.5 (VIN), R82.1, C82.1, D82.1 (K), U82.5 (VIN), R83.1, C83.1, D83.1 (K), U83.5 (VIN), R84.1, C84.1, D84.1 (K), U84.5 (VIN), R85.1, C85.1, D85.1 (K), U85.5 (VIN), R86.1, C86.1, D86.1 (K), U86.5 (VIN), R87.1, C87.1, D87.1 (K), U87.5 (VIN), R88.1, C88.1, D88.1 (K), U88.5 (VIN), R89.1, C89.1, D89.1 (K), U89.5 (VIN), R90.1, C90.1, D90.1 (K), U90.5 (VIN), R91.1, C91.1, D91.1 (K), U91.5 (VIN), R92.1, C92.1, D92.1 (K), U92.5 (VIN), R93.1, C93.1, D93.1 (K), U93.5 (VIN), R94.1, C94.1, D94.1 (K), U94.5 (VIN), R95.1, C95.1, D95.1 (K), U95.5 (VIN), R96.1, C96.1, D96.1 (K), U96.5 (VIN), U110.1 (VIN), C110.1, C101.1, C102.1, C103.1, C104.1, J12.1 (Pin_1), J7.1, J8.1 (Pin_1), D102.1 (K), TP1.1
- **SW_5V**: U110.2 (OUT), L101.1, D101.1 (K), TP6.1
- **+5V**: L101.2, C111.1, U110.3 (FB), J10.19 (Pin_19), R203.1, TP2.1

## Fan output (control board)

- **FAN_PWM**: R201.1, J10.9 (Pin_9)
- **FAN_G**: Q1.1 (G), R201.2, R202.1
- **FAN_SW**: J8.2 (Pin_2), Q1.3 (D), D102.2 (A), TP9.1

## UI buttons + status LEDs (control board)

- **BTN_MODE**: J10.12 (Pin_12), SW1.1 (A), SW1.2 (B)
- **BTN_UP**: J10.11 (Pin_11), SW2.1 (A), SW2.2 (B)
- **BTN_DOWN**: J10.10 (Pin_10), SW3.1 (A), SW3.2 (B)
- **LED_STATUS**: J11.13 (Pin_13), R204.1
- **LED_FAULT**: J10.15 (Pin_15), R205.1
- **LED1_A**: R203.2, LED1.2 (A)
- **LED2_A**: R204.2, LED2.2 (A)
- **LED3_A**: R205.2, LED3.2 (A)

## I2C (control board)

- **I2C_SDA**: U101.27 (SDA), U102.27 (SDA), U103.27 (SDA), U104.27 (SDA), U105.27 (SDA), U106.27 (SDA), J11.6 (Pin_6), R210.1, U111.10 (SCL), TP7.1
- **I2C_SCL**: U101.26 (SCL), U102.26 (SCL), U103.26 (SCL), U104.26 (SCL), U105.26 (SCL), U106.26 (SCL), J11.3 (Pin_3), R211.1, U111.9 (SDA), TP8.1

Note: +24V and GND on the control board also touch every channel (see channel section) — the lists above omit per-channel members for readability. Full GND membership: every U<n>.2, C<n>.2, R<10x>.2, plus the parts listed here.

## LED board — per-well cluster (repeat for n = 1…96)

```
ribbon A pin ── LED_A<n> ── LED<n>.1 (anode, '+' silk mark)
LED<n>.2 (cathode) ──●── LED<n>.3 (thermal pad — tie to cathode)
                     └── LED_K<n> ── ribbon K pin
+3.3V ── TH<n>.1   TH<n> = 10k NTC
TH<n>.2 ──●── R<n>.1 (10k 1%; R<n>.2 → GND)
          └── NTC<n> ── mux input (see table)
```

Wells are indexed by grid position (LED1…LED96, row-major). The logical channel each well carries is CH. Table sorted by well.

| Well | row,col | CH | NTC | divider R | ribbon A / K | mux input |
|---|---|---|---|---|---|---|
| LED1 | 1,1 | 14 | TH1 | R1 | J1.29 / J1.30 | U1.2 (I7) |
| LED2 | 1,2 | 16 | TH2 | R2 | J1.33 / J1.34 | U1.23 (I8) |
| LED3 | 1,3 | 18 | TH3 | R3 | J2.3 / J2.4 | U1.3 (I6) |
| LED4 | 1,4 | 21 | TH4 | R4 | J2.9 / J2.10 | U1.22 (I9) |
| LED5 | 1,5 | 25 | TH5 | R5 | J2.17 / J2.18 | U1.4 (I5) |
| LED6 | 1,6 | 28 | TH6 | R6 | J2.25 / J2.26 | U1.21 (I10) |
| LED7 | 1,7 | 31 | TH7 | R7 | J2.31 / J2.32 | U1.5 (I4) |
| LED8 | 1,8 | 33 | TH8 | R8 | J3.1 / J3.2 | U1.20 (I11) |
| LED9 | 1,9 | 36 | TH9 | R9 | J3.7 / J3.8 | U1.6 (I3) |
| LED10 | 1,10 | 40 | TH10 | R10 | J3.15 / J3.16 | U1.19 (I12) |
| LED11 | 1,11 | 44 | TH11 | R11 | J3.25 / J3.26 | U1.7 (I2) |
| LED12 | 1,12 | 48 | TH12 | R12 | J3.33 / J3.34 | U1.18 (I13) |
| LED13 | 2,1 | 9 | TH13 | R13 | J1.17 / J1.18 | U1.8 (I1) |
| LED14 | 2,2 | 12 | TH14 | R14 | J1.25 / J1.26 | U1.17 (I14) |
| LED15 | 2,3 | 13 | TH15 | R15 | J1.27 / J1.28 | U1.9 (I0) |
| LED16 | 2,4 | 17 | TH16 | R16 | J2.1 / J2.2 | U1.16 (I15) |
| LED17 | 2,5 | 20 | TH17 | R17 | J2.7 / J2.8 | U2.2 (I7) |
| LED18 | 2,6 | 24 | TH18 | R18 | J2.15 / J2.16 | U2.23 (I8) |
| LED19 | 2,7 | 29 | TH19 | R19 | J2.27 / J2.28 | U2.3 (I6) |
| LED20 | 2,8 | 32 | TH20 | R20 | J2.33 / J2.34 | U2.22 (I9) |
| LED21 | 2,9 | 35 | TH21 | R21 | J3.5 / J3.6 | U2.4 (I5) |
| LED22 | 2,10 | 39 | TH22 | R22 | J3.13 / J3.14 | U2.21 (I10) |
| LED23 | 2,11 | 43 | TH23 | R23 | J3.23 / J3.24 | U2.5 (I4) |
| LED24 | 2,12 | 47 | TH24 | R24 | J3.31 / J3.32 | U2.20 (I11) |
| LED25 | 3,1 | 5 | TH25 | R25 | J1.9 / J1.10 | U2.6 (I3) |
| LED26 | 3,2 | 7 | TH26 | R26 | J1.13 / J1.14 | U2.19 (I12) |
| LED27 | 3,3 | 8 | TH27 | R27 | J1.15 / J1.16 | U2.7 (I2) |
| LED28 | 3,4 | 11 | TH28 | R28 | J1.23 / J1.24 | U2.18 (I13) |
| LED29 | 3,5 | 15 | TH29 | R29 | J1.31 / J1.32 | U2.8 (I1) |
| LED30 | 3,6 | 22 | TH30 | R30 | J2.11 / J2.12 | U2.17 (I14) |
| LED31 | 3,7 | 23 | TH31 | R31 | J2.13 / J2.14 | U2.9 (I0) |
| LED32 | 3,8 | 27 | TH32 | R32 | J2.23 / J2.24 | U2.16 (I15) |
| LED33 | 3,9 | 34 | TH33 | R33 | J3.3 / J3.4 | U3.2 (I7) |
| LED34 | 3,10 | 38 | TH34 | R34 | J3.11 / J3.12 | U3.23 (I8) |
| LED35 | 3,11 | 42 | TH35 | R35 | J3.21 / J3.22 | U3.3 (I6) |
| LED36 | 3,12 | 46 | TH36 | R36 | J3.29 / J3.30 | U3.22 (I9) |
| LED37 | 4,1 | 1 | TH37 | R37 | J1.1 / J1.2 | U3.4 (I5) |
| LED38 | 4,2 | 2 | TH38 | R38 | J1.3 / J1.4 | U3.21 (I10) |
| LED39 | 4,3 | 3 | TH39 | R39 | J1.5 / J1.6 | U3.5 (I4) |
| LED40 | 4,4 | 4 | TH40 | R40 | J1.7 / J1.8 | U3.20 (I11) |
| LED41 | 4,5 | 6 | TH41 | R41 | J1.11 / J1.12 | U3.6 (I3) |
| LED42 | 4,6 | 10 | TH42 | R42 | J1.21 / J1.22 | U3.19 (I12) |
| LED43 | 4,7 | 19 | TH43 | R43 | J2.5 / J2.6 | U3.7 (I2) |
| LED44 | 4,8 | 26 | TH44 | R44 | J2.21 / J2.22 | U3.18 (I13) |
| LED45 | 4,9 | 30 | TH45 | R45 | J2.29 / J2.30 | U3.8 (I1) |
| LED46 | 4,10 | 37 | TH46 | R46 | J3.9 / J3.10 | U3.17 (I14) |
| LED47 | 4,11 | 41 | TH47 | R47 | J3.17 / J3.18 | U3.9 (I0) |
| LED48 | 4,12 | 45 | TH48 | R48 | J3.27 / J3.28 | U3.16 (I15) |
| LED49 | 5,1 | 64 | TH49 | R49 | J4.33 / J4.34 | U4.2 (I7) |
| LED50 | 5,2 | 63 | TH50 | R50 | J4.31 / J4.32 | U4.23 (I8) |
| LED51 | 5,3 | 62 | TH51 | R51 | J4.29 / J4.30 | U4.3 (I6) |
| LED52 | 5,4 | 60 | TH52 | R52 | J4.25 / J4.26 | U4.22 (I9) |
| LED53 | 5,5 | 56 | TH53 | R53 | J4.15 / J4.16 | U4.4 (I5) |
| LED54 | 5,6 | 53 | TH54 | R54 | J4.9 / J4.10 | U4.21 (I10) |
| LED55 | 5,7 | 67 | TH55 | R55 | J5.5 / J5.6 | U4.5 (I4) |
| LED56 | 5,8 | 71 | TH56 | R56 | J5.13 / J5.14 | U4.20 (I11) |
| LED57 | 5,9 | 78 | TH57 | R57 | J5.29 / J5.30 | U4.6 (I3) |
| LED58 | 5,10 | 85 | TH58 | R58 | J6.9 / J6.10 | U4.19 (I12) |
| LED59 | 5,11 | 89 | TH59 | R59 | J6.17 / J6.18 | U4.7 (I2) |
| LED60 | 5,12 | 93 | TH60 | R60 | J6.27 / J6.28 | U4.18 (I13) |
| LED61 | 6,1 | 61 | TH61 | R61 | J4.27 / J4.28 | U4.8 (I1) |
| LED62 | 6,2 | 59 | TH62 | R62 | J4.23 / J4.24 | U4.17 (I14) |
| LED63 | 6,3 | 58 | TH63 | R63 | J4.21 / J4.22 | U4.9 (I0) |
| LED64 | 6,4 | 54 | TH64 | R64 | J4.11 / J4.12 | U4.16 (I15) |
| LED65 | 6,5 | 49 | TH65 | R65 | J4.1 / J4.2 | U5.2 (I7) |
| LED66 | 6,6 | 69 | TH66 | R66 | J5.9 / J5.10 | U5.23 (I8) |
| LED67 | 6,7 | 74 | TH67 | R67 | J5.21 / J5.22 | U5.3 (I6) |
| LED68 | 6,8 | 77 | TH68 | R68 | J5.27 / J5.28 | U5.22 (I9) |
| LED69 | 6,9 | 82 | TH69 | R69 | J6.3 / J6.4 | U5.4 (I5) |
| LED70 | 6,10 | 86 | TH70 | R70 | J6.11 / J6.12 | U5.21 (I10) |
| LED71 | 6,11 | 90 | TH71 | R71 | J6.21 / J6.22 | U5.5 (I4) |
| LED72 | 6,12 | 94 | TH72 | R72 | J6.29 / J6.30 | U5.20 (I11) |
| LED73 | 7,1 | 57 | TH73 | R73 | J4.17 / J4.18 | U5.6 (I3) |
| LED74 | 7,2 | 55 | TH74 | R74 | J4.13 / J4.14 | U5.19 (I12) |
| LED75 | 7,3 | 51 | TH75 | R75 | J4.5 / J4.6 | U5.7 (I2) |
| LED76 | 7,4 | 66 | TH76 | R76 | J5.3 / J5.4 | U5.18 (I13) |
| LED77 | 7,5 | 70 | TH77 | R77 | J5.11 / J5.12 | U5.8 (I1) |
| LED78 | 7,6 | 72 | TH78 | R78 | J5.15 / J5.16 | U5.17 (I14) |
| LED79 | 7,7 | 76 | TH79 | R79 | J5.25 / J5.26 | U5.9 (I0) |
| LED80 | 7,8 | 80 | TH80 | R80 | J5.33 / J5.34 | U5.16 (I15) |
| LED81 | 7,9 | 83 | TH81 | R81 | J6.5 / J6.6 | U6.2 (I7) |
| LED82 | 7,10 | 87 | TH82 | R82 | J6.13 / J6.14 | U6.23 (I8) |
| LED83 | 7,11 | 91 | TH83 | R83 | J6.23 / J6.24 | U6.3 (I6) |
| LED84 | 7,12 | 95 | TH84 | R84 | J6.31 / J6.32 | U6.22 (I9) |
| LED85 | 8,1 | 52 | TH85 | R85 | J4.7 / J4.8 | U6.4 (I5) |
| LED86 | 8,2 | 50 | TH86 | R86 | J4.3 / J4.4 | U6.21 (I10) |
| LED87 | 8,3 | 65 | TH87 | R87 | J5.1 / J5.2 | U6.5 (I4) |
| LED88 | 8,4 | 68 | TH88 | R88 | J5.7 / J5.8 | U6.20 (I11) |
| LED89 | 8,5 | 73 | TH89 | R89 | J5.17 / J5.18 | U6.6 (I3) |
| LED90 | 8,6 | 75 | TH90 | R90 | J5.23 / J5.24 | U6.19 (I12) |
| LED91 | 8,7 | 79 | TH91 | R91 | J5.31 / J5.32 | U6.7 (I2) |
| LED92 | 8,8 | 81 | TH92 | R92 | J6.1 / J6.2 | U6.18 (I13) |
| LED93 | 8,9 | 84 | TH93 | R93 | J6.7 / J6.8 | U6.8 (I1) |
| LED94 | 8,10 | 88 | TH94 | R94 | J6.15 / J6.16 | U6.17 (I14) |
| LED95 | 8,11 | 92 | TH95 | R95 | J6.25 / J6.26 | U6.9 (I0) |
| LED96 | 8,12 | 96 | TH96 | R96 | J6.33 / J6.34 | U6.16 (I15) |

## LED board — muxes

All six CD74HC4067: pin 24 (VCC) → +3.3V with 100nF (C1-C6), pin 12 (GND) → GND, pin 15 (/E) → GND (always enabled).

| Signal | Mux pins | Ribbon |
|---|---|---|
| MUX_A0 | U1-U6 pin 10 (S0) | J9.15 |
| MUX_A1 | U1-U6 pin 11 (S1) | J9.16 |
| MUX_A2 | U1-U6 pin 14 (S2) | J9.17 |
| MUX_A3 | U1-U6 pin 13 (S3) | J9.18 |
| NTC_SIG1 | U1 pin 1 (COM) | J9.3 |
| NTC_SIG2 | U2 pin 1 (COM) | J9.5 |
| NTC_SIG3 | U3 pin 1 (COM) | J9.7 |
| NTC_SIG4 | U4 pin 1 (COM) | J9.9 |
| NTC_SIG5 | U5 pin 1 (COM) | J9.11 |
| NTC_SIG6 | U6 pin 1 (COM) | J9.13 |

## Ribbon cables (straight 1:1, keyed)

J1-J6 (40-way): each ribbon carries 16 channels as pin-pairs. Pairs 1-9 on pins 1-18, pairs 10-16 on pins 21-34; pin 20 UNUSED (IDE-cable key), pins 19 and 35-40 = GND. A = odd pin, K = even pin of each pair. Which well and which driver land on each slot is in the channel map above (they differ per board — the cable is a straight 1:1).

J9 (20-way):

| Pin | Signal | Pin | Signal |
|---|---|---|---|
| 1 | +3.3V | 2 | GND |
| 3 | NTC_SIG1 | 4 | GND |
| 5 | NTC_SIG2 | 6 | GND |
| 7 | NTC_SIG3 | 8 | GND |
| 9 | NTC_SIG4 | 10 | GND |
| 11 | NTC_SIG5 | 12 | GND |
| 13 | NTC_SIG6 | 14 | GND |
| 15 | MUX_A0 | 16 | MUX_A1 |
| 17 | MUX_A2 | 18 | MUX_A3 |
| 19 | GND | 20 | GND |

**24V does NOT cross the ribbons.** Feed 24 V to the control board (J6 screw terminal or J7 barrel jack). The LED board needs no direct 24 V — every LED is powered through its channel pair.

## Test points

**LED board:** TP1 = +3.3V, TP2 = GND, TP3 = GND

**Control board:** TP1 = +24V, TP2 = +5V, TP3 = +3.3V, TP4 = GND, TP5 = GND, TP6 = SW_5V, TP7 = I2C_SDA, TP8 = I2C_SCL, TP9 = FAN_SW, TP10 = DIM1, TP11 = LED_A33, TP12 = LED_K33

## ERC housekeeping

- Add power symbols (+24V, +5V, +3.3V, GND) and one PWR_FLAG on +24V, +5V, +3.3V and GND (they enter via connectors).
- U111 (ADS1115) is DNP — wire it anyway (ADDR pin 1 → GND = 0x48) so it can be populated later; or leave unwired and ignore ERC.
- Unused mux inputs: none (all 16 used on all six).
- Unused PCA9685 outputs: none (96 = 6×16 exactly).

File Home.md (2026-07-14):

---
tags: [96-well-led-array, dashboard]
---

# 96-Well Plate LED Array — Home

660 nm illuminator for a standard **96-well microplate**: 12×8 LEDs at 9 mm
(SBS well pitch), one LED per well, **per-well dimming + per-well temperature
sensing**, ESP32-controlled, JLCPCB-fabricated.

## Start here

- [[notes/Architecture|Architecture]] — how the two boards work
- [[CONNECTIONS|Wiring guide (CONNECTIONS.md)]] — every net, pin by pin ← *wire the schematics from this*
- [[notes/Design Decisions|Design Decisions]] — why each part/topology was chosen
- [[notes/Parts and BOM|Parts and BOM]] — every component with LCSC numbers
- [[notes/What Every Part Does|What Every Part Does]] — plain-language purpose of every part
- [[notes/Bring-Up Checklist|Bring-Up Checklist]] — first power-on procedure
- [[notes/Firmware Plan|Firmware Plan]] — ESP32 pin map + software sketch
- [[README|README]] — GitHub-facing overview

## Files

- KiCad LED board: `12x8 Led Array 9mm pitch/`
- KiCad control board: `control-board/`
- Schematic PDFs: [[docs/led-board-schematic.pdf|LED board PDF]] · [[docs/control-board-schematic.pdf|control board PDF]]
- Datasheets: `reference/datasheets/` (named by part + usage)
- Generators: `scripts/` (`design_data.py` = single source of truth)

## Status

| Stage | State |
|---|---|
| Parts selection (JLCPCB-stocked) | ✅ done |
| Schematics (parts placed, verified pinouts) | ✅ done — **awaiting your review** |
| Wiring | ⬜ you, per [[CONNECTIONS]] |
| PCB placement | ⏸ drafts exist, on hold until schematics verified |
| JLCPCB BOM/CPL | ⬜ after LCSC verification agent returns |
| Order + bring-up | ⬜ |

## Quick facts

- 96 × Hongli 3535 660 nm LED (3 W-rated) run at **256 mA ≈ 0.5 W** → ~50 W panel
- One **PT4115** buck constant-current channel per LED; PWM via 6 × PCA9685
- 96 × 10k NTC → six 16:1 muxes → 6 ESP32 ADC pins
- LEDs are **wavelength-swappable** (any 3535 3-pad part, ~1.5–3.4 V Vf) — see [[notes/Design Decisions#LED swapability]]

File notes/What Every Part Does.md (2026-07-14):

---
tags: [96-well-led-array, reference]
---

# What Every Part Does

Plain-language tour of every component, grouped by job. Quantities are per
board set.

## The light itself (LED board)

- **LED1–LED96 — 660nm LEDs (3535 package).** One per well of the 96-well
  plate. 3W-rated but run at 256mA (~0.5W) for lifetime and thermal headroom.
  Pad 1 = anode, pad 2 = cathode, center pad = heat outlet (tied to cathode).
- **TH1–TH96 — 10k NTC thermistors.** One beside each LED; resistance drops
  as temperature rises. This is the per-well thermometer.
- **R1–R96 (LED board) — 10k 1% resistors.** The bottom half of each NTC's
  voltage divider: 3.3V → NTC → *measure here* → 10k → GND. The midpoint
  voltage encodes the well temperature.
- **U1–U6 — CD74HC4067 analog multiplexers (16:1).** Each connects 16 NTC
  divider midpoints, one at a time, onto a single output wire. Six of them
  turn 96 analog signals into 6 wires + 4 shared address lines.
- **C1–C6 — 100nF decoupling capacitors.** Local energy reservoirs that keep
  each mux's supply steady when it switches.

## Making constant current (control board, ×96 each)

- **U1–U96 — PT4115 buck LED drivers.** The heart of each channel: a tiny
  switching regulator that chops 24V down to whatever its LED needs while
  holding current constant. Has a DIM input for brightness control.
- **R1–R96 — 0.39Ω 1% sense resistors.** The PT4115 measures the voltage
  across this to know the current: 0.1V ÷ 0.39Ω = 256mA. Change this value
  to change LED current.
- **L1–L96 — 47µH inductors.** The energy-storage element of each buck
  converter; smooths the chopped 24V into steady LED current.
- **D1–D96 — SS34 Schottky diodes.** The "freewheel" path: when the PT4115's
  switch opens, inductor current keeps flowing through this diode. Band
  faces +24V.
- **C1–C96 — 2.2µF 50V capacitors.** Per-channel input reservoir so each
  converter's current pulses don't disturb its neighbors.
- **R101–R196 — 100k pulldowns.** Safety: a floating PT4115 DIM pin means
  FULL brightness, so these hold every channel OFF until the ESP32 says
  otherwise. The panel cannot boot bright.

## Brightness control

- **U101–U106 — PCA9685 16-channel PWM chips.** The ESP32 tells them over
  I2C what brightness each channel should be; they generate 96 independent
  PWM signals (~244Hz, ~10-11 usable bits) into the PT4115 DIM pins.
  One chip = one 16-channel bank = one ribbon cable.
- **C121–C126 — 100nF decoupling** for each PCA9685.
- **R210, R211 — 4.7k I2C pullups.** I2C lines idle high; these provide the
  pull. One pair serves the whole bus.

## Power conversion

- **J12 (screw terminal) / J7 (barrel jack) — 24V input.** Two options for
  the same input; use either.
- **C101–C104 — 220µF bulk electrolytics.** Big reservoirs on the 24V rail:
  two at the input, two near the fan/load side.
- **U110 — XL1509-5.0 buck regulator.** Makes the 5V logic rail from 24V.
- **L101 (47µH), D101 (SS34), C110 (100µF in), C111 (220µF out)** — the
  XL1509's supporting cast: same buck-converter roles as in the LED channels.
- The ESP32 dev board's own regulator then makes 3.3V from the 5V rail for
  all logic.

## Brains and interface

- **J10, J11 — 1×19 socket headers.** The ESP32 DevKitC-38 plugs in here;
  socketed so you can pull it for programming or replacement.
- **U111 — ADS1115 16-bit ADC (not fitted by default).** Insurance: if the
  ESP32's built-in ADC proves too noisy for the NTC readings, solder this in
  and read temperatures over I2C instead.
- **SW1–SW3 — tactile buttons (MODE / UP / DOWN).** Front-panel control
  without a computer.
- **LED1–LED3 (control board) — indicator LEDs.** Green = 5V power present
  (hardwired), blue = status heartbeat, red = fault latch. **R203–R205** set
  their brightness.
- **Q1 — AO3400 MOSFET.** Low-side switch so the ESP32 can PWM a 24V fan.
  **R201** (100Ω) tames its gate; **R202** (100k) keeps it off at boot;
  **D102** (SS34) absorbs the fan motor's inductive kick. **J8** is the fan
  plug.

## Connecting the two boards

- **J1–J6 (both boards) — 40-pin IDC ribbon headers.** Each carries one
  PCA9685 bank: 16 channels × (anode + cathode) on pins 1-18 and 21-34.
  Pin 20 is deliberately unused so keyed IDE cables work; pin 19 and 35-40
  are grounds. Cheap 40-pin ribbon cables connect them 1:1.
- **J9 (both boards) — 20-pin IDC logic ribbon.** Carries 3.3V, the six mux
  outputs, the four mux address lines, and grounds between boards.
- **TP1–TP12 — test points.** Bare pads for probing rails and one full
  debug channel (DIM1/LED_A1/LED_K1) during bring-up.
- **H1–H5 — M3 mounting holes.** Standoffs; the two boards share the same
  hole spacing so the sandwich bolts together.

## Copper that acts like a component

- **Thermal via farms (5 per LED)** — copper tubes carrying heat from each
  LED's pad through the board to the back face.
- **Cathode islands (96, back of LED board)** — heat-spreading pads under
  each LED, pressed against the heatsink through an insulating pad.
- **Inner planes** — solid GND and +24V sheets inside both boards: quiet
  return paths for 96 switching converters and effortless power delivery.

Related: [[Parts and BOM]] (part numbers & prices) · [[Architecture]] ·
[[../CONNECTIONS|CONNECTIONS]]

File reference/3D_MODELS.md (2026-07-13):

# 3D Model Status

Audit of every footprint in `scripts/design_data.py` `FP{}` (2026-07-13).
Stock models live under `${KICAD10_3DMODEL_DIR}` (`C:\Program Files\KiCad\10.0\share\kicad\3dmodels`);
project models under `libraries/jlc_parts.3dshapes/`, referenced as
`${KIPRJMOD}/../libraries/jlc_parts.3dshapes/<file>` (both `.kicad_pro` files sit one level below repo root).

## Status table

| FP key | Footprint | Model | Status |
|---|---|---|---|
| led | jlc_parts:LED-SMD_3P-L3.5-W3.5_NLW3535AV2 | jlc_parts.3dshapes/LED-SMD_3P-L3.5-W3.5_NLW3535AV2.wrl | OK (path fixed) |
| pt4115 | jlc_parts:SOT-89-5_L4.5-W2.5-P1.50-LS4.5-BR | jlc_parts.3dshapes/SOT-89-5_L4.5-W2.5-H1.5-LS4.1-P1.50.wrl | OK (path fixed) |
| mux | jlc_parts:SOIC-24_L15.4-W7.5-P1.27-LS10.3-BL | jlc_parts.3dshapes/SOIC-24_L15.4-W7.5-H2.7-LS10.3-P1.27.wrl | OK (path fixed) |
| button | jlc_parts:SW-SMD_4P-L5.1-W5.1-P3.70-LS6.5-TL_H1.5 | jlc_parts.3dshapes/SW-SMD_4P-...-TL_H1.5.wrl | OK (path fixed) |
| screw2 | jlc_parts:TerminalBlock_KF301-5.0-2P_1x02_P5.00mm | jlc_parts.3dshapes/CONN-TH_P5.00_KF301-5.0-2P.wrl | OK (was broken, see below) |
| r0603 | Resistor_SMD:R_0603_1608Metric | Resistor_SMD.3dshapes/R_0603_1608Metric.step | OK |
| r0805 | Resistor_SMD:R_0805_2012Metric | Resistor_SMD.3dshapes/R_0805_2012Metric.step | OK |
| c0603 | Capacitor_SMD:C_0603_1608Metric | Capacitor_SMD.3dshapes/C_0603_1608Metric.step | OK |
| c0805 | Capacitor_SMD:C_0805_2012Metric | Capacitor_SMD.3dshapes/C_0805_2012Metric.step | OK |
| elec8 | Capacitor_SMD:CP_Elec_8x10 | Capacitor_SMD.3dshapes/CP_Elec_8x10.step | OK |
| elec63 | Capacitor_SMD:CP_Elec_6.3x7.7 | Capacitor_SMD.3dshapes/CP_Elec_6.3x7.7.step | OK |
| led0805 | LED_SMD:LED_0805_2012Metric | LED_SMD.3dshapes/LED_0805_2012Metric.step | OK |
| sma | Diode_SMD:D_SMA | Diode_SMD.3dshapes/D_SMA.step | OK |
| swpa4030 | Inductor_SMD:L_Sunlord_SWPA4030S | Inductor_SMD.3dshapes/L_Sunlord_SWPA4030S.step | OK |
| swpa6045 | Inductor_SMD:L_Sunlord_SWPA6045S | Inductor_SMD.3dshapes/L_Sunlord_SWPA6045S.step | OK |
| soic8 | Package_SO:SOIC-8_3.9x4.9mm_P1.27mm | Package_SO.3dshapes/SOIC-8_3.9x4.9mm_P1.27mm.step | OK |
| tssop28 | Package_SO:TSSOP-28_4.4x9.7mm_P0.65mm | Package_SO.3dshapes/TSSOP-28_4.4x9.7mm_P0.65mm.step | OK |
| vssop10 | Package_SO:TSSOP-10_3x3mm_P0.5mm | Package_SO.3dshapes/TSSOP-10_3x3mm_P0.5mm.step | OK |
| sot23 | Package_TO_SOT_SMD:SOT-23 | Package_TO_SOT_SMD.3dshapes/SOT-23.step | OK |
| idc50 | Connector_IDC:IDC-Header_2x25_P2.54mm_Vertical | Connector_IDC.3dshapes/IDC-Header_2x25_P2.54mm_Vertical.step | OK |
| idc20 | Connector_IDC:IDC-Header_2x10_P2.54mm_Horizontal | Connector_IDC.3dshapes/IDC-Header_2x10_P2.54mm_Horizontal.step | OK |
| sock19 | Connector_PinSocket_2.54mm:PinSocket_1x19_P2.54mm_Vertical | Connector_PinSocket_2.54mm.3dshapes/PinSocket_1x19_P2.54mm_Vertical.step | OK |
| barrel | Connector_BarrelJack:BarrelJack_Horizontal | Connector_BarrelJack.3dshapes/BarrelJack_Horizontal.step | OK |
| hdr2 | Connector_PinHeader_2.54mm:PinHeader_1x02_P2.54mm_Vertical | Connector_PinHeader_2.54mm.3dshapes/PinHeader_1x02_P2.54mm_Vertical.step | OK |
| hole | MountingHole:MountingHole_3.2mm_M3 | — | no model (correct: it's a hole) |
| tp | TestPoint:TestPoint_Pad_1.5x1.5mm | — | no model (correct: bare copper pad, KiCad ships none for pad-type TPs) |

## Changes made

1. **jlc_parts model paths fixed** (led, pt4115, mux, button): were bare-relative
   `jlc_parts.3dshapes/<f>.wrl`, which KiCad cannot resolve from either project dir.
   Rewritten to `${KIPRJMOD}/../libraries/jlc_parts.3dshapes/<f>.wrl` in
   `libraries/jlc_parts.pretty/*.kicad_mod` **and** in the embedded copies inside both
   `.kicad_pcb` files (regenerating via `scripts/gen_pcbs.py` now also produces the fixed paths).
2. **KF301 screw terminal (J6, C474881)**: previously referenced
   `${KICAD10_3DMODEL_DIR}/TerminalBlock.3dshapes/TerminalBlock_MaiXu_MX126-...step`,
   which does not exist in KiCad 10 (no generic `TerminalBlock.3dshapes` lib ships).
   Fetched the real KF301-5.0-2P model via
   `easyeda2kicad --3d --lcsc_id C474881` →
   `libraries/jlc_parts.3dshapes/CONN-TH_P5.00_KF301-5.0-2P.{step,wrl}` (STEP verified ISO-10303-21).
   Footprint + embedded PCB copy now reference the WRL with **offset (2.5, 0, 0) mm**
   (EasyEDA footprint origin = pin midpoint; ours = pin 1, pin 2 at +5 mm; same body
   orientation, rotation 0). The easyeda2kicad-generated duplicate footprint
   `CONN-TH_P5.00_KF301-5.0-2P.kicad_mod` was deleted; design keeps
   `TerminalBlock_KF301-5.0-2P_1x02_P5.00mm` (1.4 mm drills).
3. **ESP32-DevKitC-38** full-board STEP added:
   `libraries/jlc_parts.3dshapes/ESP32-DevKitC-38.step` (7.6 MB, verified ISO-10303-21,
   products: board / ESP32-WROOM-32D / micro usb / buttons). Source: SnapEDA/Espressif
   "ESP32-DEVKITC-32D" model as redistributed in github.com/BlueAndi/Pixelix
   (`doc/boards/pixelix/v2.1/3D-files/`). No WRL exists for it; STEP renders fine in KiCad.
   **Not attached to any footprint** — see below.

## Attaching the DevKitC model (manual step)

The module plugs into two `PinSocket_1x19` (J10 left/3V3 row at (140, 130), J11 right/GND
row at (165.4, 130), rows 25.4 mm apart, pins running +y). Attach the model to **J10 only**:

PCB editor → J10 → Footprint Properties → 3D Models → add
`${KIPRJMOD}/../libraries/jlc_parts.3dshapes/ESP32-DevKitC-38.step` with:

| Offset X | Offset Y | Offset Z | Rot X | Rot Y | Rot Z |
|---|---|---|---|---|---|
| +12.7 mm | −22.86 mm | +8.5 mm | −90° | 0° | 0° |

Rationale: the STEP's insertion point is the center of the 2×19 pin field with the board
in the XZ plane (convention confirmed from the Pixelix reference footprint, which uses
offset (0, −3, 3.5) / rotate (−90, 0, 0) on a footprint whose origin is that center).
X +12.7 = half the 25.4 mm row spacing from J10's pin 1; Y −22.86 = half the 45.72 mm pin
span (dialog +Y is up in board view); Z +8.5 = socket insulator height, i.e. module PCB
underside resting on the sockets. Check in the 3D viewer: if the module faces the wrong
way (antenna end swapped), set Rot Z = 180° and keep the same offsets; nudge Z to taste.

## Remaining gaps

- None blocking: every populated footprint resolves a model. MountingHole and
  TestPoint_Pad intentionally have no 3D model.
- DevKitC model is not auto-attached (J10/J11 are generic pin sockets shared by both
  rows); attach manually per the table above, or add the `(model ...)` block to J10's
  footprint instance in `control-board.kicad_pcb` / teach `gen_pcbs.py` to inject it.
- WRL variant of the DevKitC model unavailable (STEP only).

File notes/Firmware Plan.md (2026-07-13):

---
tags: [96-well-led-array, firmware]
---

# Firmware Plan (ESP32 DevKitC-38)

## Pin map

| GPIO | Function |
|---|---|
| 21 / 22 | I2C SDA/SCL @ 400 kHz → 6× PCA9685 (0x40-0x45), opt. ADS1115 (0x48) |
| 16 / 17 / 18 / 19 | Mux address S0-S3 (shared across all six muxes) |
| 32 / 33 / 34 / 35 / 36 / 39 | ADC1 ← NTC_SIG1-6 (muxes U1-U6) |
| 25 | Fan PWM (25 kHz LEDC, low-side AO3400A) |
| 4 / 13 | STATUS (blue) / FAULT (red) LEDs |
| 14 / 27 / 26 | Buttons MODE/UP/DOWN (to GND, `INPUT_PULLUP`) |

Note: GPIO34/35/36/39 are input-only — fine, they're ADC inputs here.

## Core loops

- **PWM**: PCA9685 prescale ≈ 244 Hz (see [[Design Decisions#Dimming]]).
  Well n → chip `(n-1)//16` (0x40+k), output `LED[(n-1)%16]`. Full-frame
  update ≈ 90 Hz max — plenty.
- **Thermal scan**: set S0-S3, wait ≥200 µs, read 6 ADCs (one per mux) →
  6 wells per address step, 96 wells in 16 steps, full sweep well under
  100 ms. Convert ratiometrically (B=3434, 10k/10k divider); calibrate ADC
  with `esp_adc_cal`.
- **Derating**: per-well PI or simple threshold — above 75 °C scale that
  well's duty down; above 85 °C zero it and set FAULT. Log over serial/WiFi.
- **Boot**: all duties 0, ramp to setpoint over ~1 s ([[Design
  Decisions#Boot safety]]).

## UI sketch

MODE cycles presets (off / 10 % / 50 % / 100 % / chaser test), UP/DOWN trim,
STATUS blinks heartbeat, FAULT latches on any thermal event until MODE held.

## Libraries

Arduino-ESP32 or ESP-IDF; Adafruit PWM Servo Driver library works for
PCA9685 (it's the same chip as their servo board), or ~50 lines of raw I2C.

Related: [[Bring-Up Checklist]] · [[../CONNECTIONS|CONNECTIONS]]

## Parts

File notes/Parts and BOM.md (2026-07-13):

---
tags: [96-well-led-array, bom]
---

# Parts and BOM

All parts from the JLCPCB/LCSC library, stock checked and **re-verified**
2026-07-13 (see `reference/datasheets/PART_VERIFICATION.json`). Datasheets in
`reference/datasheets/` (named `PART_usage_MFR_C#.pdf`).

Verification notes: C25804 (10k Basic) had zero stock on 2026-07-13 —
fallback C98220 (Yageo, Extended). C9144 is the **right-angle** 2×10 IDC
variant (footprint set accordingly); straight alternatives are low-stock.

## LED board

| Part | Qty | LCSC | Role |
|---|---|---|---|
| Hongli HL-C3535F15R3GA-ZW | 96 (order 110) | C5445086 | 660 nm well emitter |
| Murata NCP18XH103F03RB 0603 | 96 | C13564 | per-well NTC |
| 10k 1% 0603 | 96 | C25804 | NTC divider lower leg |
| CD74HC4067M96 | 6 | C496123 | 16:1 NTC mux (backup: Nexperia C117943) |
| 100nF 0603 | 6 | C14663 | mux decoupling |
| IDC 2×25 box header | 4 | C9044 | channel ribbons (hand-solder) |
| IDC 2×10 box header | 1 | C9144 | logic ribbon (hand-solder) |

## Control board

| Part | Qty | LCSC | Role |
| --- | --- | --- | --- |
| PT4115 (UMW) SOT-89-5 | 96 | C347356 | per-well buck CC driver |
| 0.39 Ω 1% 0805 | 96 | C2930218 | sense → 256 mA |
| SWPA4030S470MT 47 µH | 96 | C54731 | channel inductor |
| SS34 SMA | 98 | C8678 | freewheel ×96 + 5V buck + fan flyback |
| 2.2 µF 50 V 0805 | 96 | C125847 | channel VIN cap (Yageo X7R) |
| 100k 0603 | 97 | C25803 | DIM pulldowns + fan gate pulldown |
| PCA9685PW | 6 | C2678753 | 16-ch PWM (addr 0x40-0x45) |
| 100nF 0603 | 6 | C14663 | PCA decoupling |
| XL1509-5.0E1 | 1 | C61063 | 24→5 V logic rail (Basic ✓) |
| SWPA6045S470MT 47 µH | 1 | C36414 | 5V buck inductor |
| 100 µF 50 V elec | 1 | C134514 | 5V buck input (Lelon 8×10) |
| 220 µF 16 V elec | 1 | C286136 | 5V rail output (Lelon 6.3mm) |
| 220 µF 35 V elec | 4 | C134820 | 24 V bulk (Lelon 8×10) |
| KF301-5.0-2P | 1 | C474881 | 24 V screw terminal |
| DC-005-5A-2.5 | 1 | C381115 | 24 V barrel jack (5 A) |
| AO3400A | 1 | C20917 | fan low-side switch (Basic ✓) |
| 100R 0603 | 1 | C22775 | fan gate series |
| TS-1187A-B-A-B | 3 | C318884 | MODE/UP/DOWN buttons |
| LED 0805 green/blue/red | 1+1+1 | C2297/C2293/C84256 | PWR/STATUS/FAULT (green/red Basic) |
| 2.2k + 1k 0603 | 1+2 | C4190/C21190 | indicator series R (Basic) |
| 4.7k 0603 | 2 | C23162 | I2C pullups |
| ADS1115IDGSR | 1 (DNP) | C37593 | optional precision ADC |
| Pin socket 1×19 | 2 | C319202 | ESP32 DevKitC socket (hand-solder) |
| Pin header 1×02 | 1 | C2337 | fan connector (1×40 breakaway, snap 2)|
| IDC 2×25 / 2×10 | 4 / 1 | C9044/C9144 | ribbons (hand-solder) |

## Off-BOM purchases

- 24 V ≥4 A power brick (5.5×2.5 mm plug or bare leads to screw terminal)
- Finned heatsink ≥ 110×70 mm + **insulating** thermal pad + M3 hardware
- 4× 50-way + 1× 20-way 1.27 mm IDC ribbon cables
- Optional 24 V fan
- ESP32 DevKitC-38 (already owned)

## Cost ballpark

Parts ≈ $75/set · PCBs+assembly ≈ $120-180 (2 assembled sets, SMD single
side, THT self-soldered) · brick/heatsink/ribbons ≈ $50 → **$300-400 total**.

Related: [[Design Decisions]] · [[../CONNECTIONS|CONNECTIONS]]

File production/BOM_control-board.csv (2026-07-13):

Comment | Designator | Footprint | LCSC
2.2uF 50V | C1,C10,C11,C12,C13,C14,C15,C16,C17,C18,C19,C2,C20,C21,C22,C23,C24,C25,C26,C27,C28,C29,C3,C30,C31,C32,C33,C34,C35,C36,C37,C38,C39,C4,C40,C41,C42,C43,C44,C45,C46,C47,C48,C49,C5,C50,C51,C52,C53,C54,C55,C56,C57,C58,C59,C6,C60,C61,C62,C63,C64,C65,C66,C67,C68,C69,C7,C70,C71,C72,C73,C74,C75,C76,C77,C78,C79,C8,C80,C81,C82,C83,C84,C85,C86,C87,C88,C89,C9,C90,C91,C92,C93,C94,C95,C96 | C_0805_2012Metric | C125847
100uF 50V | C110 | CP_Elec_8x10 | C134514
220uF 35V | C101,C102,C103,C104 | CP_Elec_8x10 | C134820
100nF | C121,C122,C123,C124,C125,C126 | C_0603_1608Metric | C14663
AO3400A | Q1 | SOT-23 | C20917
1k | R204,R205 | R_0603_1608Metric | C21190
100R | R201 | R_0603_1608Metric | C22775
STATUS blue | LED2 | LED_0805_2012Metric | C2293
PWR green | LED1 | LED_0805_2012Metric | C2297
4.7k | R210,R211 | R_0603_1608Metric | C23162
100k | R101,R102,R103,R104,R105,R106,R107,R108,R109,R110,R111,R112,R113,R114,R115,R116,R117,R118,R119,R120,R121,R122,R123,R124,R125,R126,R127,R128,R129,R130,R131,R132,R133,R134,R135,R136,R137,R138,R139,R140,R141,R142,R143,R144,R145,R146,R147,R148,R149,R150,R151,R152,R153,R154,R155,R156,R157,R158,R159,R160,R161,R162,R163,R164,R165,R166,R167,R168,R169,R170,R171,R172,R173,R174,R175,R176,R177,R178,R179,R180,R181,R182,R183,R184,R185,R186,R187,R188,R189,R190,R191,R192,R193,R194,R195,R196,R202 | R_0603_1608Metric | C25803
PCA9685PW (0x40) | U101 | TSSOP-28_4.4x9.7mm_P0.65mm | C2678753
PCA9685PW (0x41) | U102 | TSSOP-28_4.4x9.7mm_P0.65mm | C2678753
PCA9685PW (0x42) | U103 | TSSOP-28_4.4x9.7mm_P0.65mm | C2678753
PCA9685PW (0x43) | U104 | TSSOP-28_4.4x9.7mm_P0.65mm | C2678753
PCA9685PW (0x44) | U105 | TSSOP-28_4.4x9.7mm_P0.65mm | C2678753
PCA9685PW (0x45) | U106 | TSSOP-28_4.4x9.7mm_P0.65mm | C2678753
220uF 16V | C111 | CP_Elec_6.3x7.7 | C286136
0.39R 1% | R1,R10,R11,R12,R13,R14,R15,R16,R17,R18,R19,R2,R20,R21,R22,R23,R24,R25,R26,R27,R28,R29,R3,R30,R31,R32,R33,R34,R35,R36,R37,R38,R39,R4,R40,R41,R42,R43,R44,R45,R46,R47,R48,R49,R5,R50,R51,R52,R53,R54,R55,R56,R57,R58,R59,R6,R60,R61,R62,R63,R64,R65,R66,R67,R68,R69,R7,R70,R71,R72,R73,R74,R75,R76,R77,R78,R79,R8,R80,R81,R82,R83,R84,R85,R86,R87,R88,R89,R9,R90,R91,R92,R93,R94,R95,R96 | R_0805_2012Metric | C2930218
MODE | SW1 | SW-SMD_4P-L5.1-W5.1-P3.70-LS6.5-TL_H1.5 | C318884
UP | SW2 | SW-SMD_4P-L5.1-W5.1-P3.70-LS6.5-TL_H1.5 | C318884
DOWN | SW3 | SW-SMD_4P-L5.1-W5.1-P3.70-LS6.5-TL_H1.5 | C318884
PT4115 | U1,U10,U11,U12,U13,U14,U15,U16,U17,U18,U19,U2,U20,U21,U22,U23,U24,U25,U26,U27,U28,U29,U3,U30,U31,U32,U33,U34,U35,U36,U37,U38,U39,U4,U40,U41,U42,U43,U44,U45,U46,U47,U48,U49,U5,U50,U51,U52,U53,U54,U55,U56,U57,U58,U59,U6,U60,U61,U62,U63,U64,U65,U66,U67,U68,U69,U7,U70,U71,U72,U73,U74,U75,U76,U77,U78,U79,U8,U80,U81,U82,U83,U84,U85,U86,U87,U88,U89,U9,U90,U91,U92,U93,U94,U95,U96 | SOT-89-5_L4.5-W2.5-P1.50-LS4.5-BR | C347356
47uH 2A+ | L101 | L_Sunlord_SWPA6045S | C36414
2.2k | R203 | R_0603_1608Metric | C4190
47uH | L1,L10,L11,L12,L13,L14,L15,L16,L17,L18,L19,L2,L20,L21,L22,L23,L24,L25,L26,L27,L28,L29,L3,L30,L31,L32,L33,L34,L35,L36,L37,L38,L39,L4,L40,L41,L42,L43,L44,L45,L46,L47,L48,L49,L5,L50,L51,L52,L53,L54,L55,L56,L57,L58,L59,L6,L60,L61,L62,L63,L64,L65,L66,L67,L68,L69,L7,L70,L71,L72,L73,L74,L75,L76,L77,L78,L79,L8,L80,L81,L82,L83,L84,L85,L86,L87,L88,L89,L9,L90,L91,L92,L93,L94,L95,L96 | L_Sunlord_SWPA4030S | C54731
XL1509-5.0E1 | U110 | SOIC-8_3.9x4.9mm_P1.27mm | C61063
FAULT red | LED3 | LED_0805_2012Metric | C84256
SS34 | D1,D10,D101,D102,D11,D12,D13,D14,D15,D16,D17,D18,D19,D2,D20,D21,D22,D23,D24,D25,D26,D27,D28,D29,D3,D30,D31,D32,D33,D34,D35,D36,D37,D38,D39,D4,D40,D41,D42,D43,D44,D45,D46,D47,D48,D49,D5,D50,D51,D52,D53,D54,D55,D56,D57,D58,D59,D6,D60,D61,D62,D63,D64,D65,D66,D67,D68,D69,D7,D70,D71,D72,D73,D74,D75,D76,D77,D78,D79,D8,D80,D81,D82,D83,D84,D85,D86,D87,D88,D89,D9,D90,D91,D92,D93,D94,D95,D96 | D_SMA | C8678

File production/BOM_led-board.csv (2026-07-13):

Comment | Designator | Footprint | LCSC
NTC 10k B3434 | TH1,TH10,TH11,TH12,TH13,TH14,TH15,TH16,TH17,TH18,TH19,TH2,TH20,TH21,TH22,TH23,TH24,TH25,TH26,TH27,TH28,TH29,TH3,TH30,TH31,TH32,TH33,TH34,TH35,TH36,TH37,TH38,TH39,TH4,TH40,TH41,TH42,TH43,TH44,TH45,TH46,TH47,TH48,TH49,TH5,TH50,TH51,TH52,TH53,TH54,TH55,TH56,TH57,TH58,TH59,TH6,TH60,TH61,TH62,TH63,TH64,TH65,TH66,TH67,TH68,TH69,TH7,TH70,TH71,TH72,TH73,TH74,TH75,TH76,TH77,TH78,TH79,TH8,TH80,TH81,TH82,TH83,TH84,TH85,TH86,TH87,TH88,TH89,TH9,TH90,TH91,TH92,TH93,TH94,TH95,TH96 | R_0603_1608Metric | C13564
100nF | C1,C2,C3,C4,C5,C6 | C_0603_1608Metric | C14663
10k 1% | R1,R10,R11,R12,R13,R14,R15,R16,R17,R18,R19,R2,R20,R21,R22,R23,R24,R25,R26,R27,R28,R29,R3,R30,R31,R32,R33,R34,R35,R36,R37,R38,R39,R4,R40,R41,R42,R43,R44,R45,R46,R47,R48,R49,R5,R50,R51,R52,R53,R54,R55,R56,R57,R58,R59,R6,R60,R61,R62,R63,R64,R65,R66,R67,R68,R69,R7,R70,R71,R72,R73,R74,R75,R76,R77,R78,R79,R8,R80,R81,R82,R83,R84,R85,R86,R87,R88,R89,R9,R90,R91,R92,R93,R94,R95,R96 | R_0603_1608Metric | C25804
CD74HC4067M96 | U1,U2,U3,U4,U5,U6 | SOIC-24_L15.4-W7.5-P1.27-LS10.3-BL | C496123
HL-C3535F15R3GA-ZW 660nm | LED1,LED10,LED11,LED12,LED13,LED14,LED15,LED16,LED17,LED18,LED19,LED2,LED20,LED21,LED22,LED23,LED24,LED25,LED26,LED27,LED28,LED29,LED3,LED30,LED31,LED32,LED33,LED34,LED35,LED36,LED37,LED38,LED39,LED4,LED40,LED41,LED42,LED43,LED44,LED45,LED46,LED47,LED48,LED49,LED5,LED50,LED51,LED52,LED53,LED54,LED55,LED56,LED57,LED58,LED59,LED6,LED60,LED61,LED62,LED63,LED64,LED65,LED66,LED67,LED68,LED69,LED7,LED70,LED71,LED72,LED73,LED74,LED75,LED76,LED77,LED78,LED79,LED8,LED80,LED81,LED82,LED83,LED84,LED85,LED86,LED87,LED88,LED89,LED9,LED90,LED91,LED92,LED93,LED94,LED95,LED96 | LED-SMD_3P-L3.5-W3.5_NLW3535AV2 | C5445086

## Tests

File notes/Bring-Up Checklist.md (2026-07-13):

---
tags: [96-well-led-array, bring-up]
---

# Bring-Up Checklist

## Before ordering

- [ ] Wire both schematics per [[../CONNECTIONS|CONNECTIONS]]; ERC clean
  (power symbols + PWR_FLAG as noted there)
- [ ] F8 sync both PCBs, route, DRC clean
- [ ] JLCPCB DFM upload; **check LED polarity in the assembly preview** — a
  rotated/mirrored LED footprint is the classic whole-board failure
- [ ] Confirm every Extended part is still in stock at order time

## Control board alone (no ribbons, no LED board)

- [ ] Visual: no solder bridges on PT4115 rows
- [ ] 24 V in via J6, current-limited bench supply if available (set 200 mA
  limit first)
- [ ] +5 V rail = 4.9-5.2 V; +3V3 present after socketing ESP32
- [ ] ESP32 I2C scan finds 0x40-0x45 (and 0x48 if ADS1115 fitted)
- [ ] All DIM lines read ~0 V (pulldowns working, panel would boot dark)
- [ ] Clip a test LED (any color, any Vf) across one channel's A/K pins;
  command 5 % duty → dim glow; 100 % → bright, current ≈ 256 mA in series
  meter

## Boards mated

- [ ] Ribbons keyed, 1:1, seated; 24 V only at control board
- [ ] All 96 wells at 5 % duty — walk a "chaser" pattern to map channel ↔ well
  and catch any swapped ribbon
- [ ] NTC scan: all 96 read ~ambient ±3 °C; heat one well with a fingertip
  and watch it move
- [ ] Mount heatsink (insulating pad!) before any run >20 % duty

## Full power soak

- [ ] 100 % duty, log max/min/spread of all 96 NTCs every 10 s
- [ ] Cathode-pad temps must stay < 85 °C (Hongli limit; 75 °C is the
  comfortable target) — set firmware derate threshold from this run
- [ ] Input current at 24 V ≈ 2.4-2.6 A
- [ ] ⚠ **Never look at the array at power** — 50 W of 660 nm at 10 cm² is an
  eye hazard. Use indirect viewing / camera.

Related: [[Firmware Plan]] · [[Architecture]]

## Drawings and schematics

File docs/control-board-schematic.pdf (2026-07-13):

LED_K23 96 DRIVER CHANNELS (CH01..CH96) - see channel.kicad_sch

RIBBONS TO LED BOARD

Sheet: /
File: control-board.kicad_sch
Title: 12x8 660nm LED Array - Control Board

Size: A1 | Rev:
KiCad E.D.A. 10.0.3 | Id: 1/97

One channel: PT4115 buck CC @ 256mA (Rs=0.39R). SS34 band to +24V. DIM: 100k pulldown = dark boot. C1

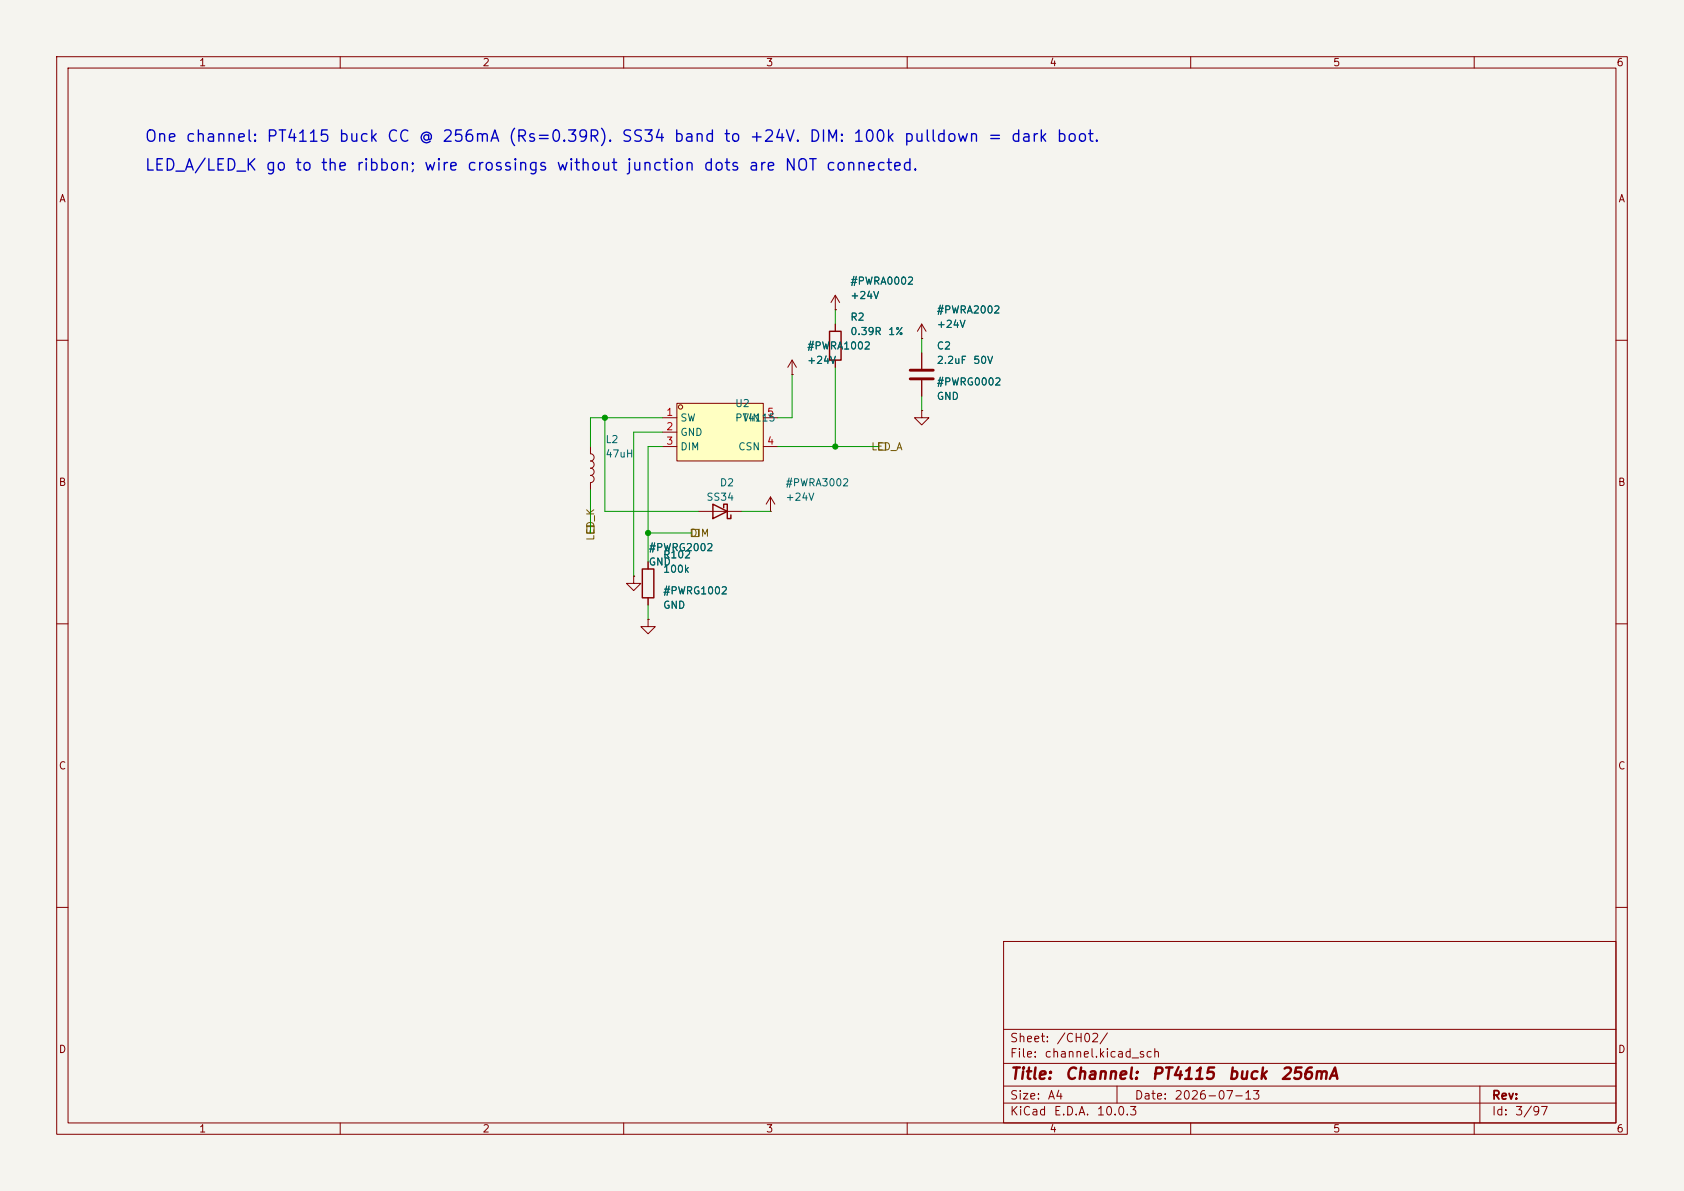
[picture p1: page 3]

One channel: PT4115 buck CC @ 256mA (Rs=0.39R). SS34 band to +24V. DIM: 100k pulldown = dark boot. C2

One channel: PT4115 buck CC @ 256mA (Rs=0.39R). SS34 band to +24V. DIM: 100k pulldown = dark boot. C3

One channel: PT4115 buck CC @ 256mA (Rs=0.39R). SS34 band to +24V. DIM: 100k pulldown = dark boot. C4

One channel: PT4115 buck CC @ 256mA (Rs=0.39R). SS34 band to +24V. DIM: 100k pulldown = dark boot. C5

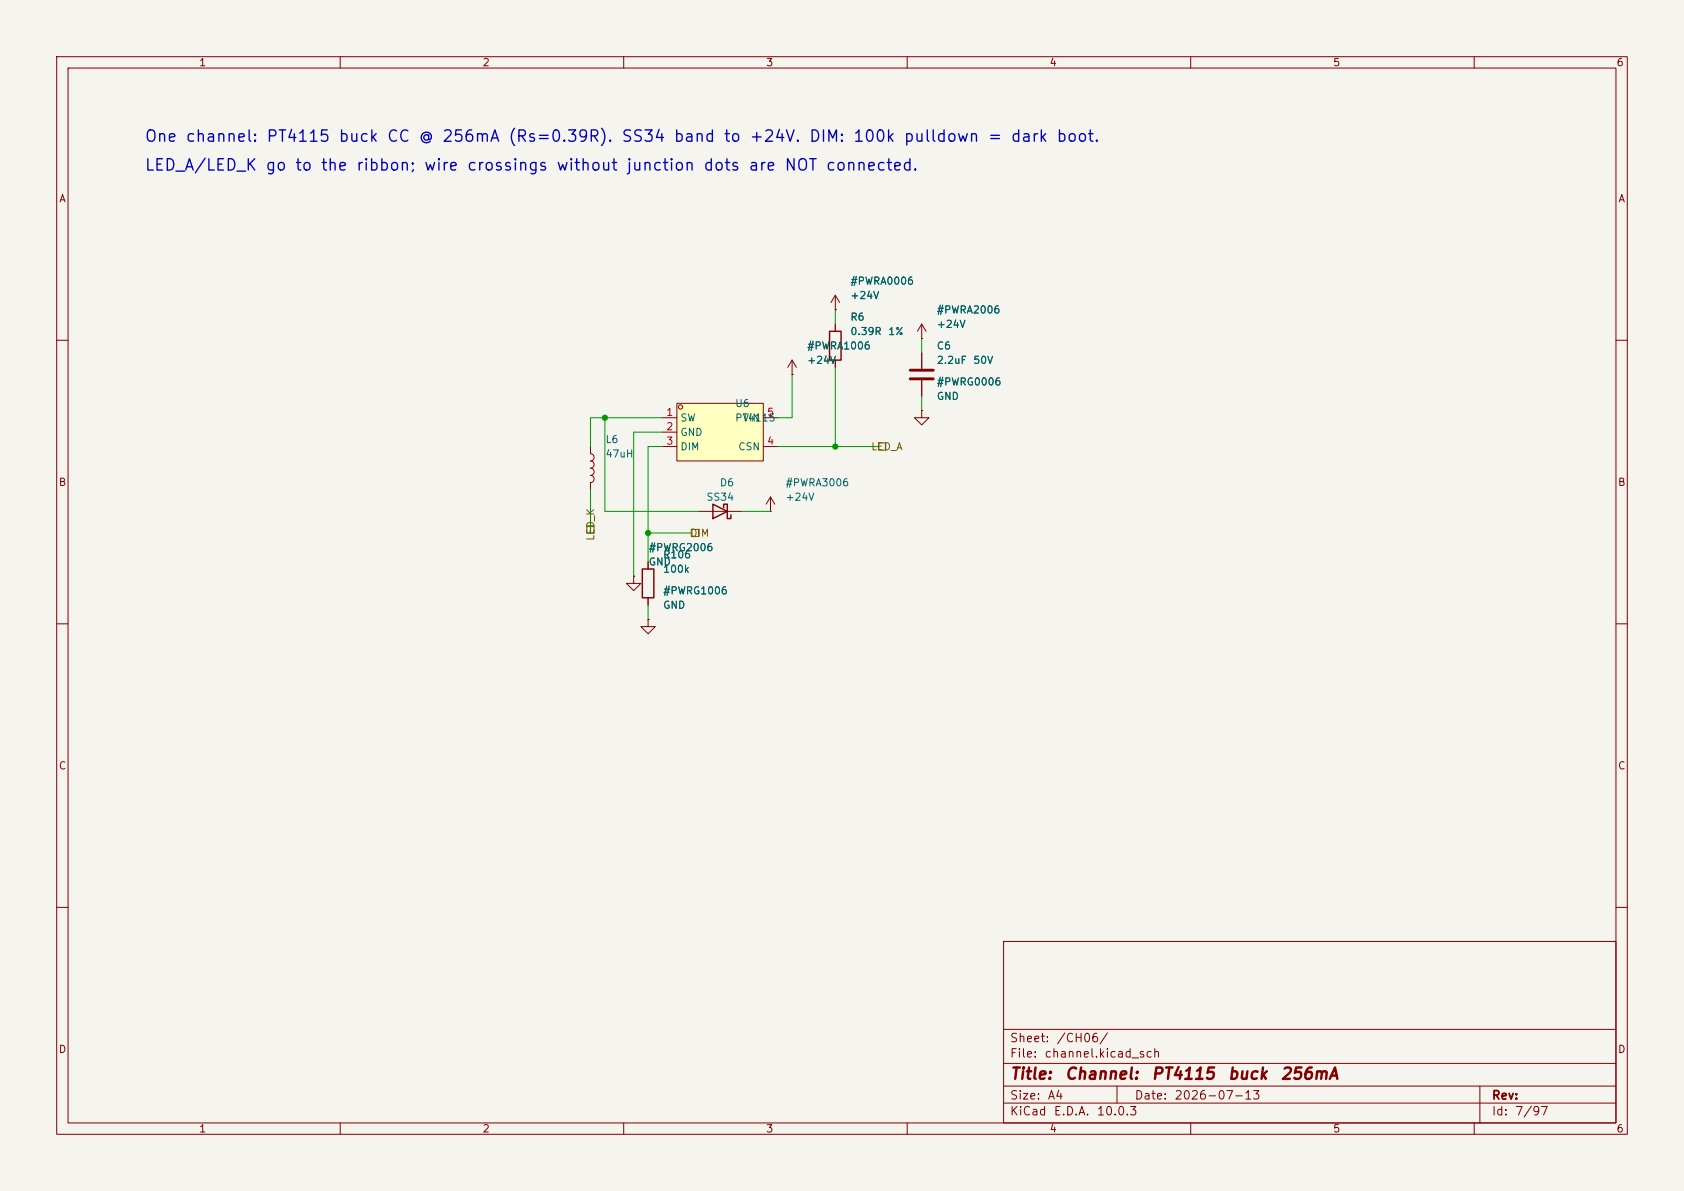
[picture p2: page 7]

One channel: PT4115 buck CC @ 256mA (Rs=0.39R). SS34 band to +24V. DIM: 100k pulldown = dark boot. C6

One channel: PT4115 buck CC @ 256mA (Rs=0.39R). SS34 band to +24V. DIM: 100k pulldown = dark boot. C7

One channel: PT4115 buck CC @ 256mA (Rs=0.39R). SS34 band to +24V. DIM: 100k pulldown = dark boot. C8

One channel: PT4115 buck CC @ 256mA (Rs=0.39R). SS34 band to +24V. DIM: 100k pulldown = dark boot. C9

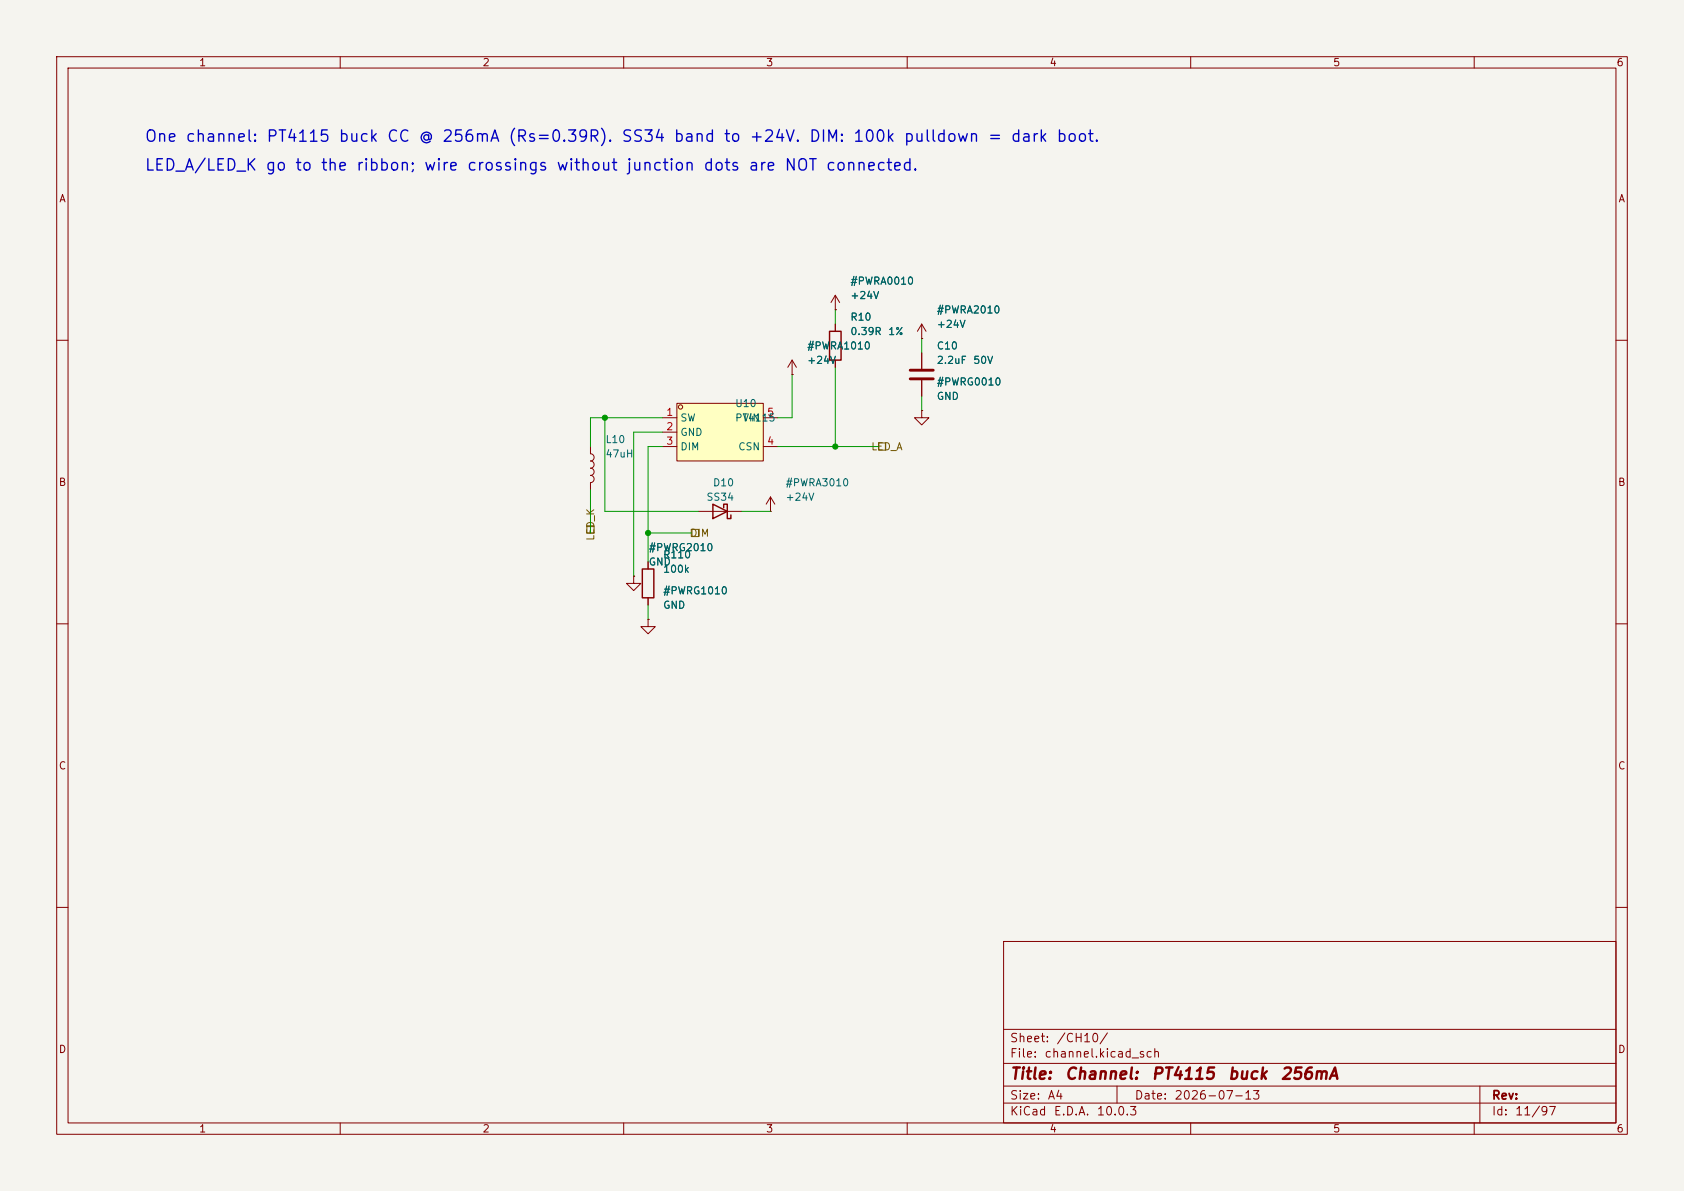
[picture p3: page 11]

One channel: PT4115 buck CC @ 256mA (Rs=0.39R). SS34 band to +24V. DIM: 100k pulldown = dark boot. C10

One channel: PT4115 buck CC @ 256mA (Rs=0.39R). SS34 band to +24V. DIM: 100k pulldown = dark boot. C11

One channel: PT4115 buck CC @ 256mA (Rs=0.39R). SS34 band to +24V. DIM: 100k pulldown = dark boot. C12

One channel: PT4115 buck CC @ 256mA (Rs=0.39R). SS34 band to +24V. DIM: 100k pulldown = dark boot. C13

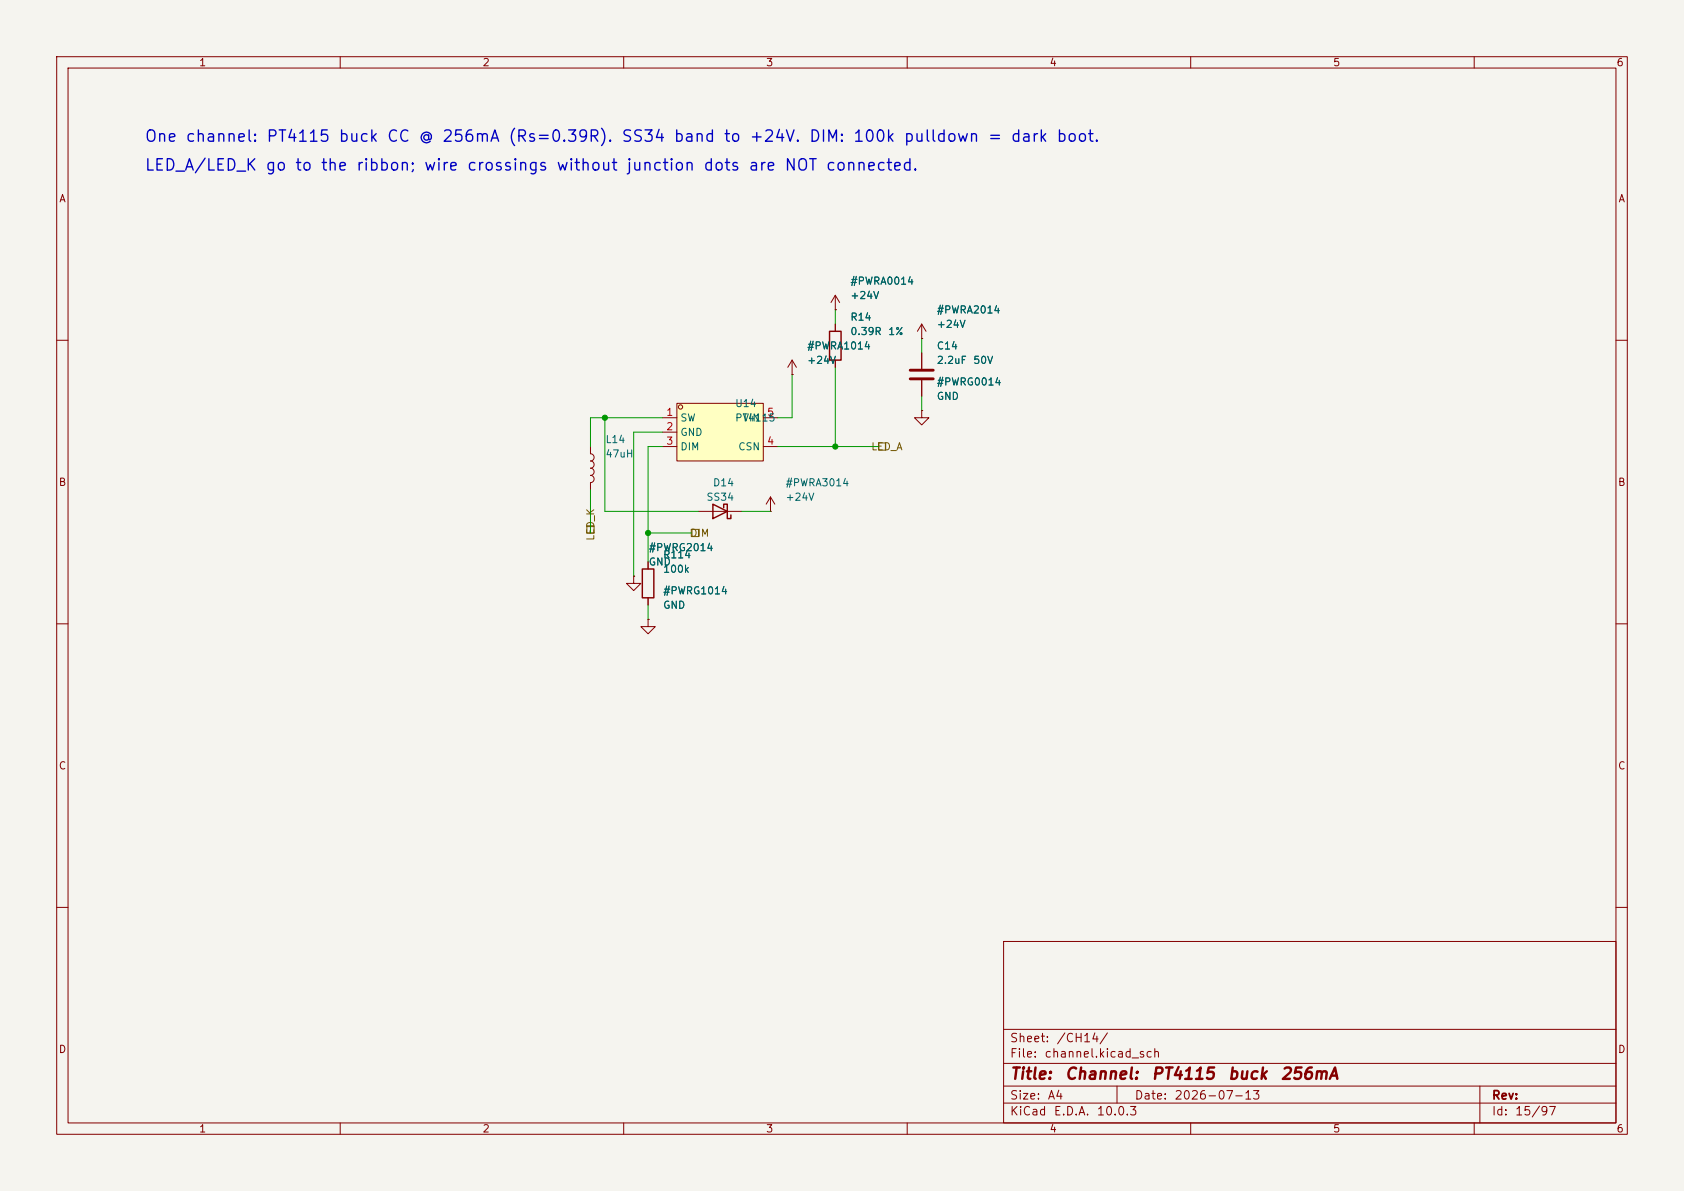
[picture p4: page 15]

One channel: PT4115 buck CC @ 256mA (Rs=0.39R). SS34 band to +24V. DIM: 100k pulldown = dark boot. C14

One channel: PT4115 buck CC @ 256mA (Rs=0.39R). SS34 band to +24V. DIM: 100k pulldown = dark boot. C15

One channel: PT4115 buck CC @ 256mA (Rs=0.39R). SS34 band to +24V. DIM: 100k pulldown = dark boot. C16

One channel: PT4115 buck CC @ 256mA (Rs=0.39R). SS34 band to +24V. DIM: 100k pulldown = dark boot. C17

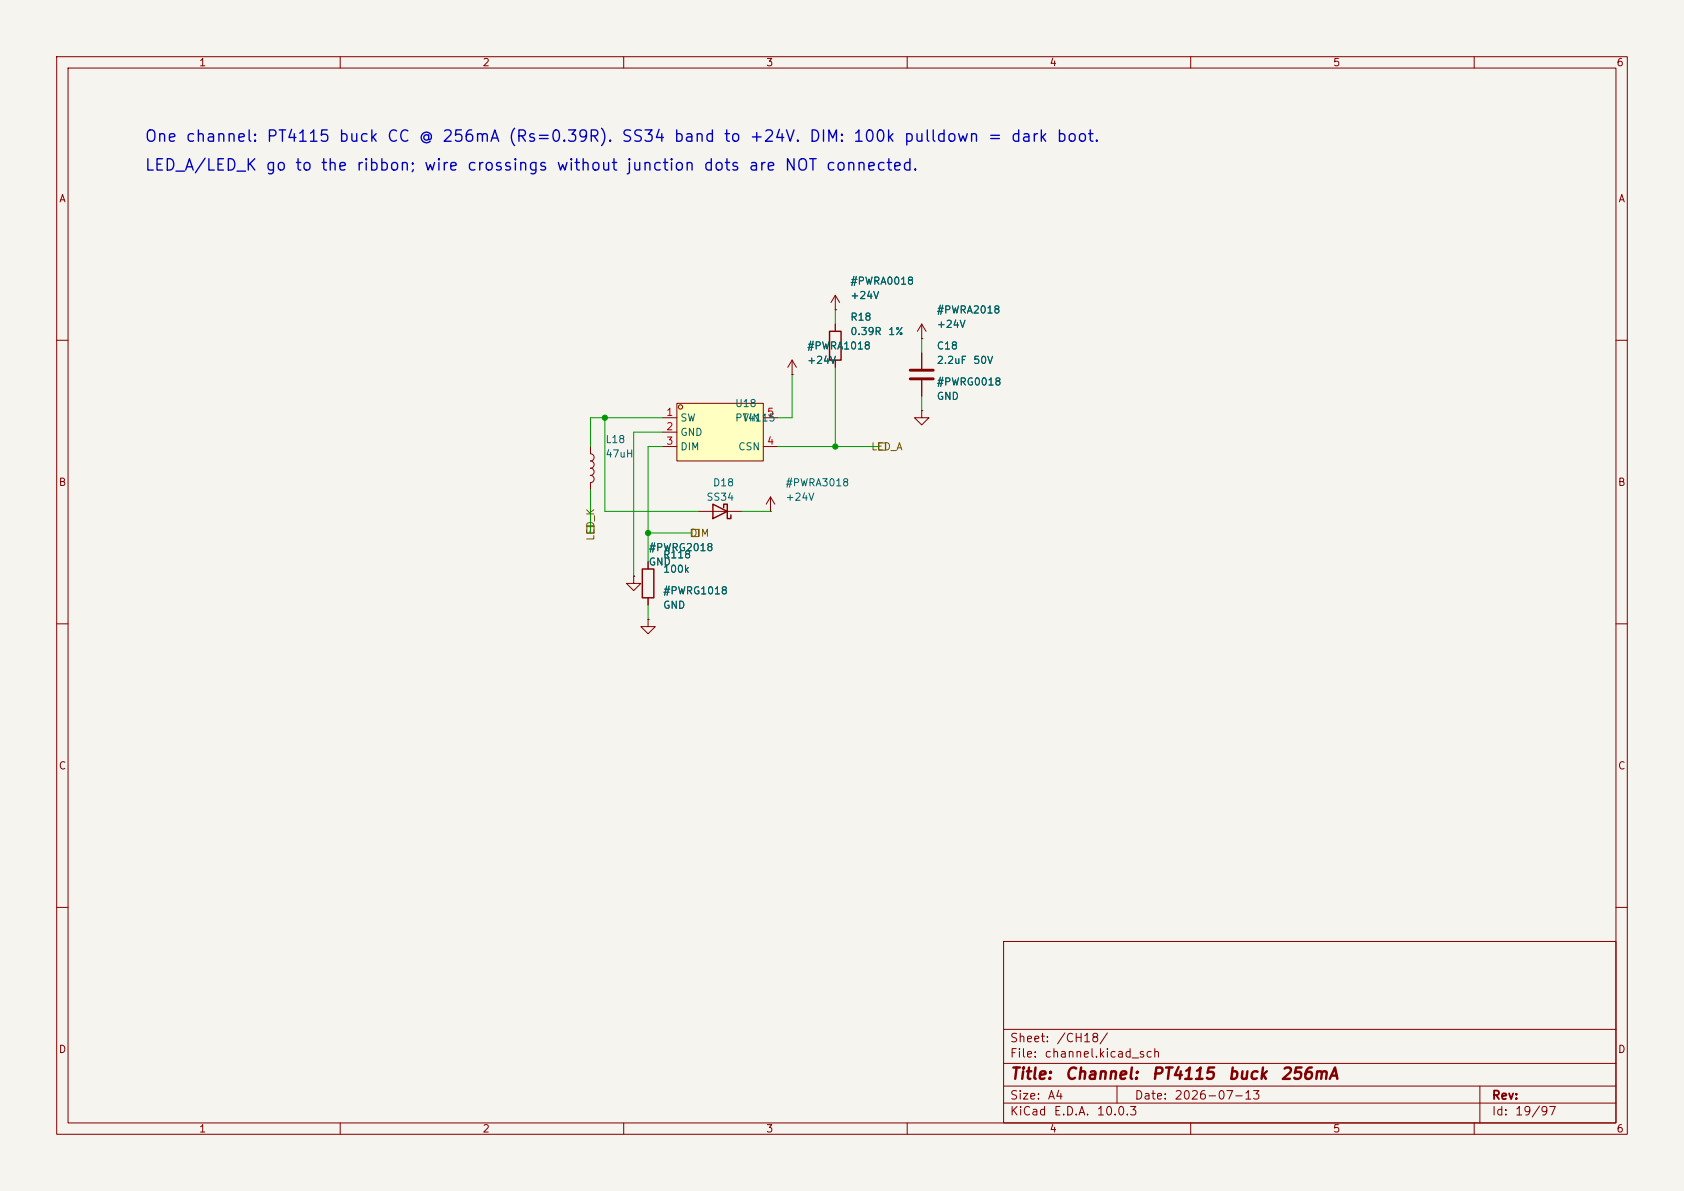
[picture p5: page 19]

One channel: PT4115 buck CC @ 256mA (Rs=0.39R). SS34 band to +24V. DIM: 100k pulldown = dark boot. C18

One channel: PT4115 buck CC @ 256mA (Rs=0.39R). SS34 band to +24V. DIM: 100k pulldown = dark boot. C19

One channel: PT4115 buck CC @ 256mA (Rs=0.39R). SS34 band to +24V. DIM: 100k pulldown = dark boot. C20

One channel: PT4115 buck CC @ 256mA (Rs=0.39R). SS34 band to +24V. DIM: 100k pulldown = dark boot. C21

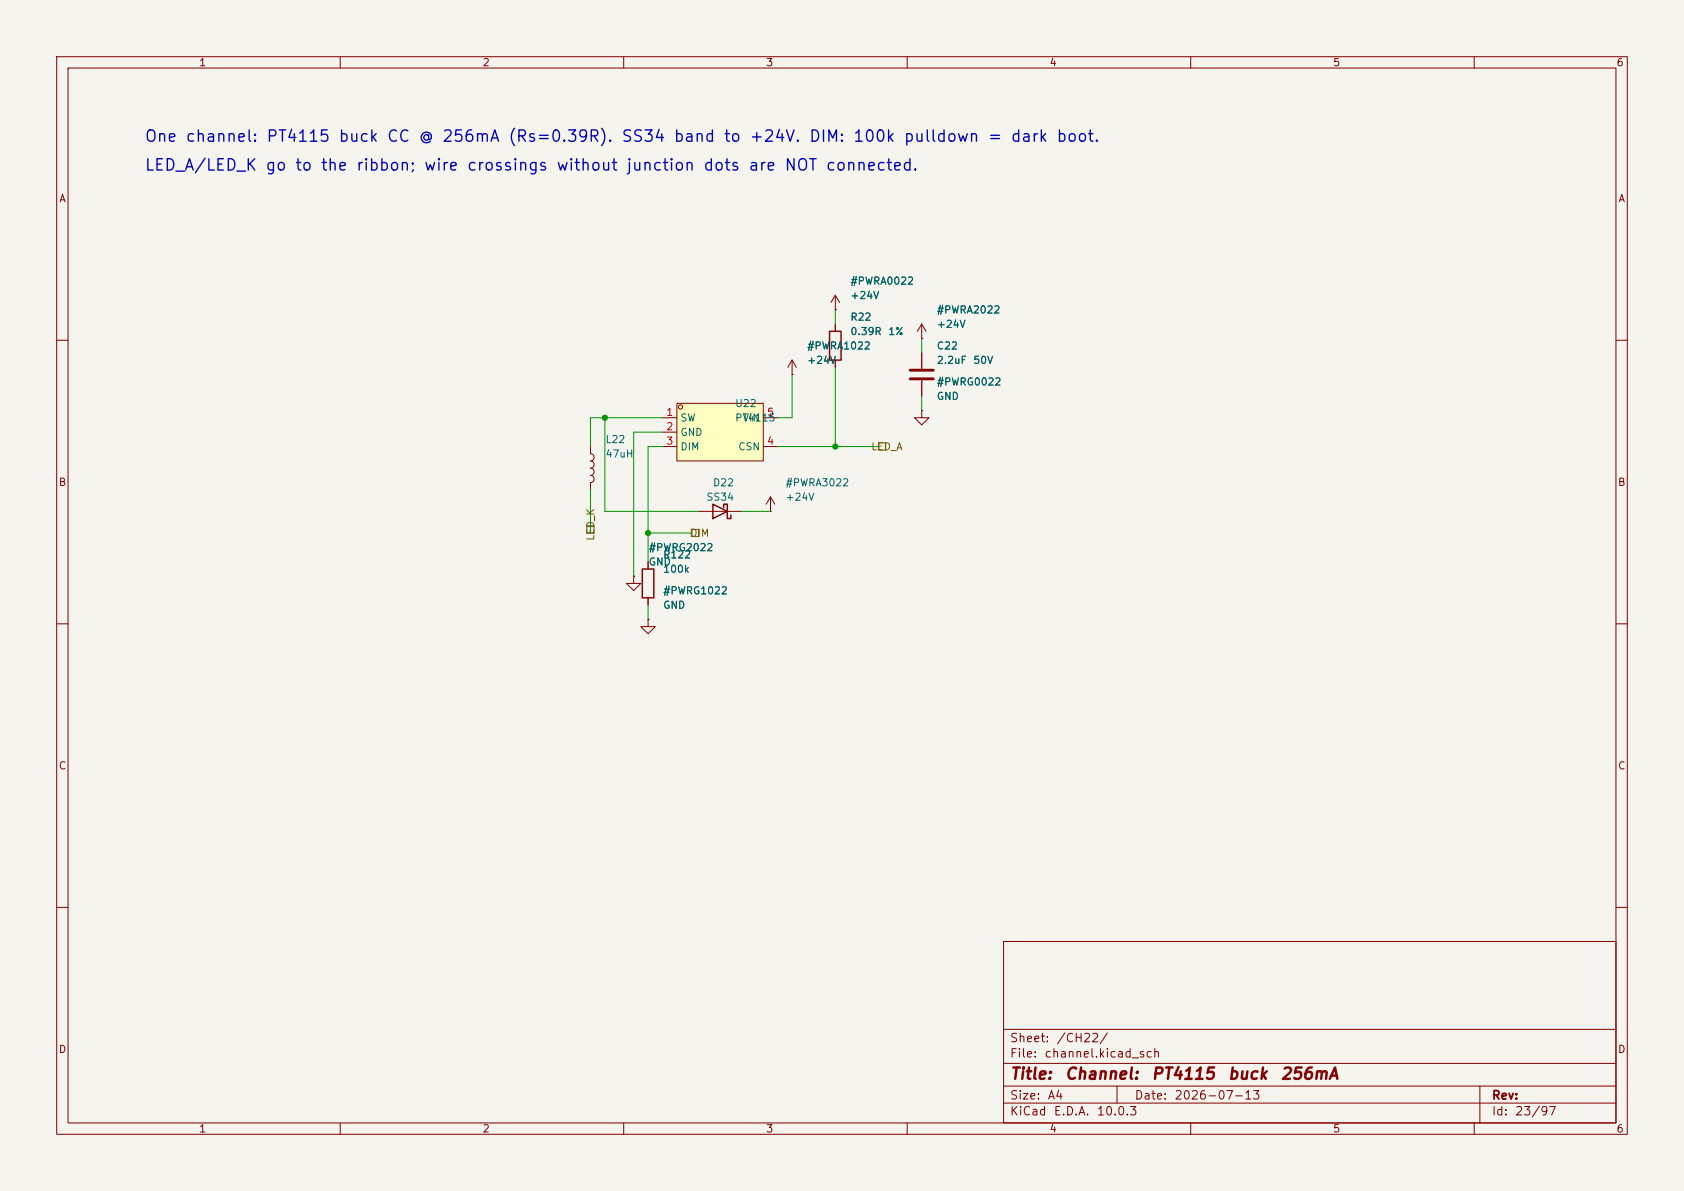
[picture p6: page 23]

One channel: PT4115 buck CC @ 256mA (Rs=0.39R). SS34 band to +24V. DIM: 100k pulldown = dark boot. C22

One channel: PT4115 buck CC @ 256mA (Rs=0.39R). SS34 band to +24V. DIM: 100k pulldown = dark boot. C23

One channel: PT4115 buck CC @ 256mA (Rs=0.39R). SS34 band to +24V. DIM: 100k pulldown = dark boot. C24

One channel: PT4115 buck CC @ 256mA (Rs=0.39R). SS34 band to +24V. DIM: 100k pulldown = dark boot. C25

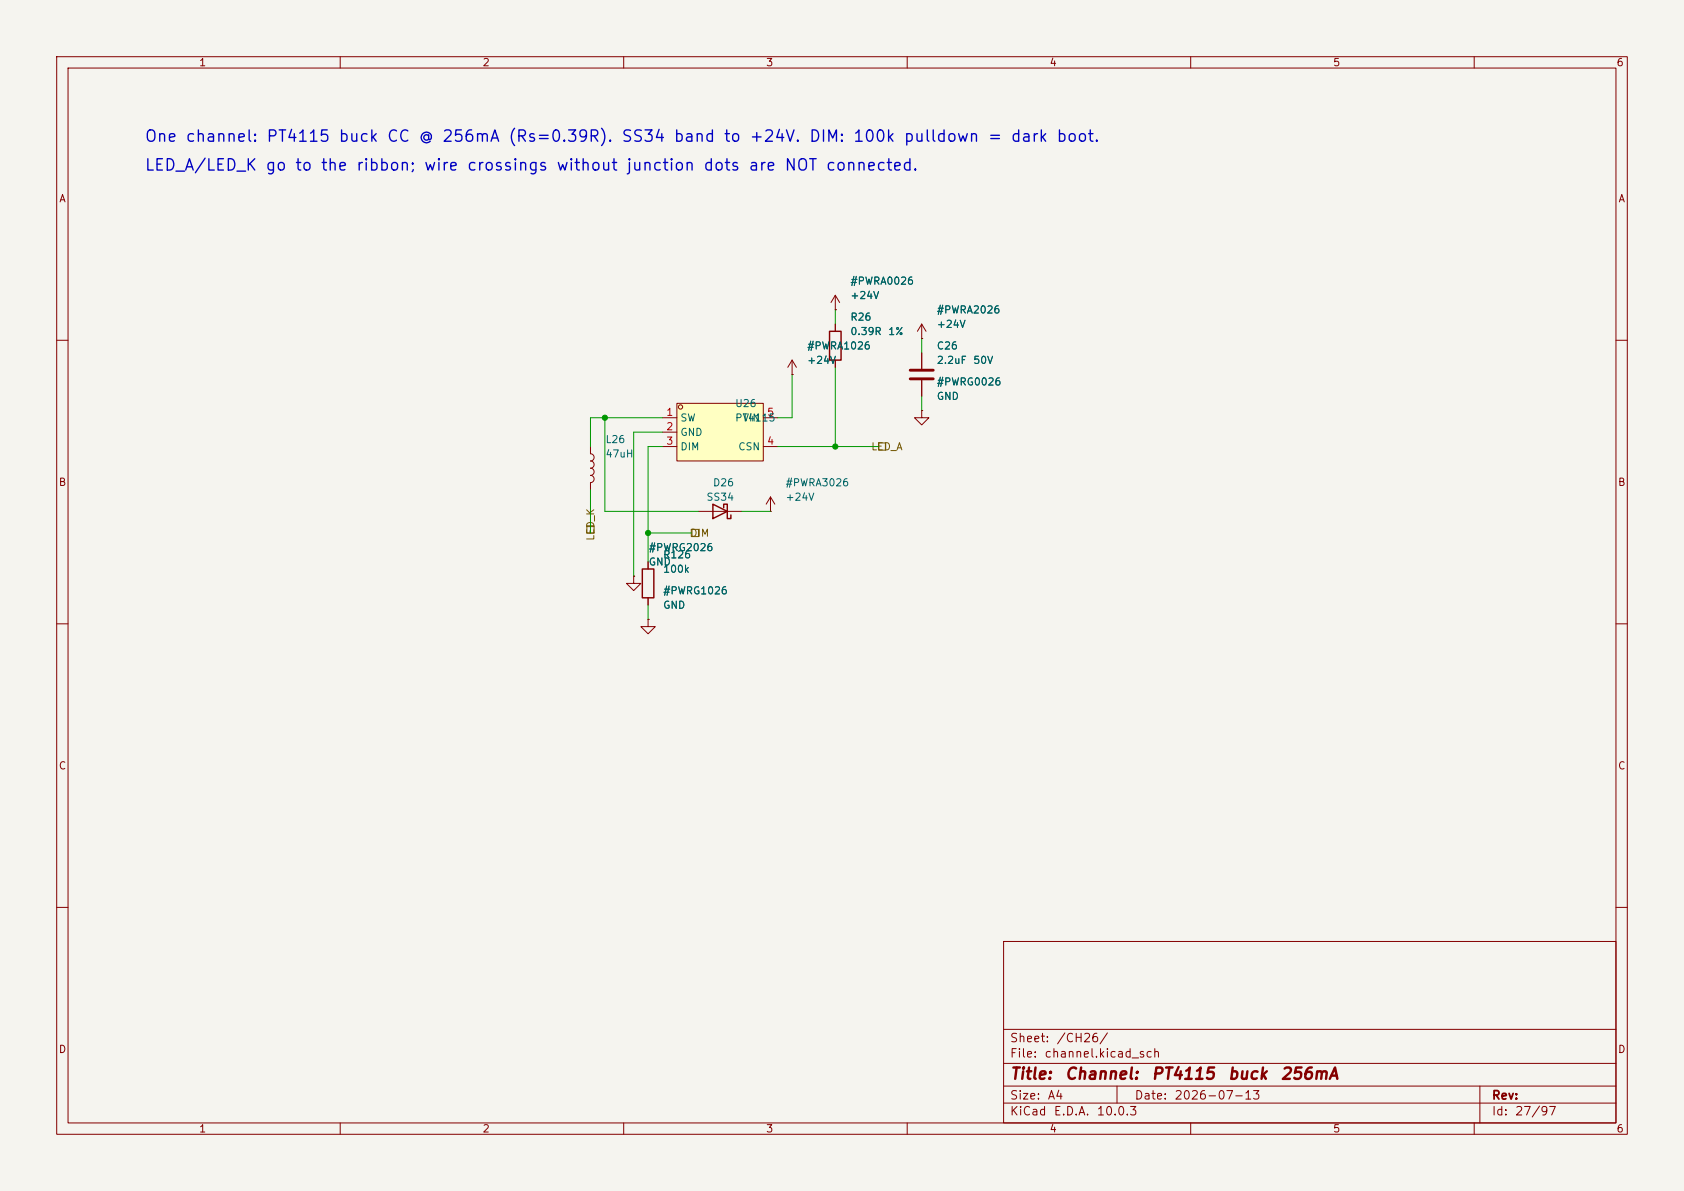
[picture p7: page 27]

One channel: PT4115 buck CC @ 256mA (Rs=0.39R). SS34 band to +24V. DIM: 100k pulldown = dark boot. C26

One channel: PT4115 buck CC @ 256mA (Rs=0.39R). SS34 band to +24V. DIM: 100k pulldown = dark boot. C27

One channel: PT4115 buck CC @ 256mA (Rs=0.39R). SS34 band to +24V. DIM: 100k pulldown = dark boot. C28

One channel: PT4115 buck CC @ 256mA (Rs=0.39R). SS34 band to +24V. DIM: 100k pulldown = dark boot. C29

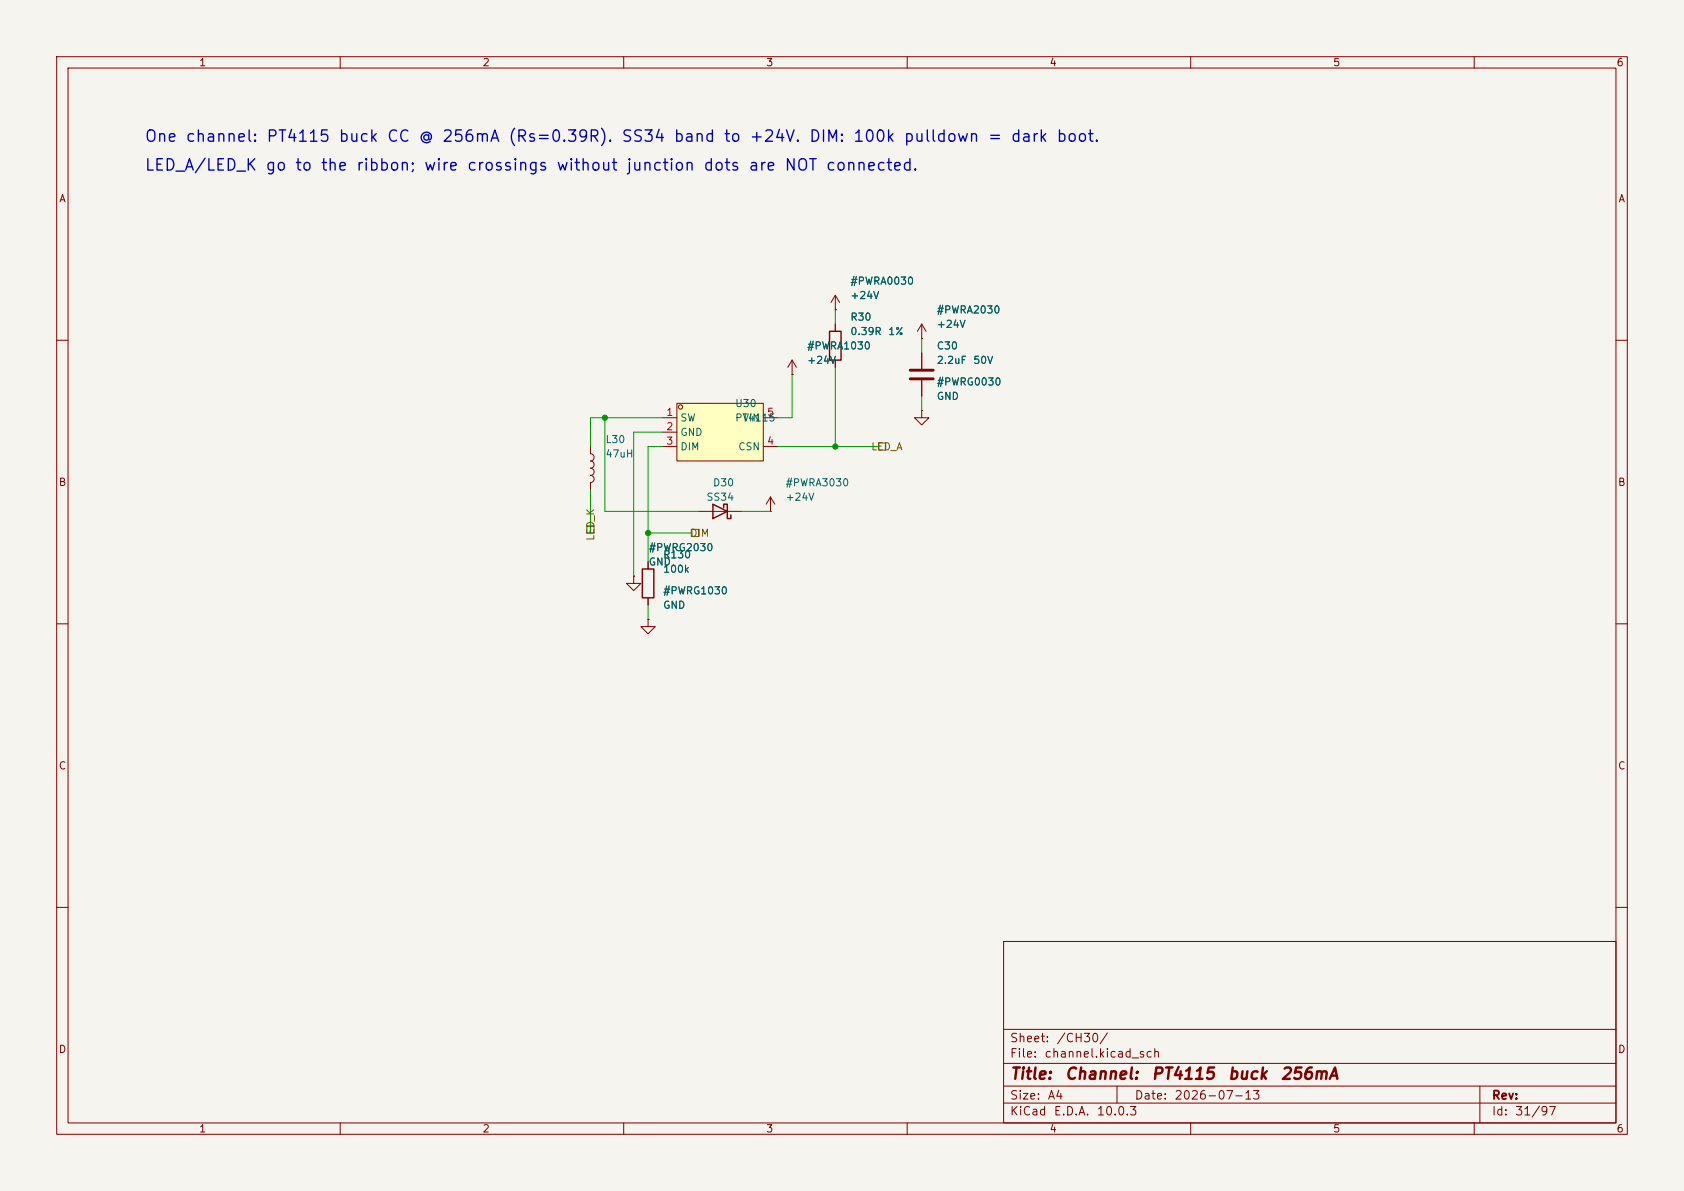
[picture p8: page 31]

One channel: PT4115 buck CC @ 256mA (Rs=0.39R). SS34 band to +24V. DIM: 100k pulldown = dark boot. C30

One channel: PT4115 buck CC @ 256mA (Rs=0.39R). SS34 band to +24V. DIM: 100k pulldown = dark boot. C31

One channel: PT4115 buck CC @ 256mA (Rs=0.39R). SS34 band to +24V. DIM: 100k pulldown = dark boot. C32

One channel: PT4115 buck CC @ 256mA (Rs=0.39R). SS34 band to +24V. DIM: 100k pulldown = dark boot. C33

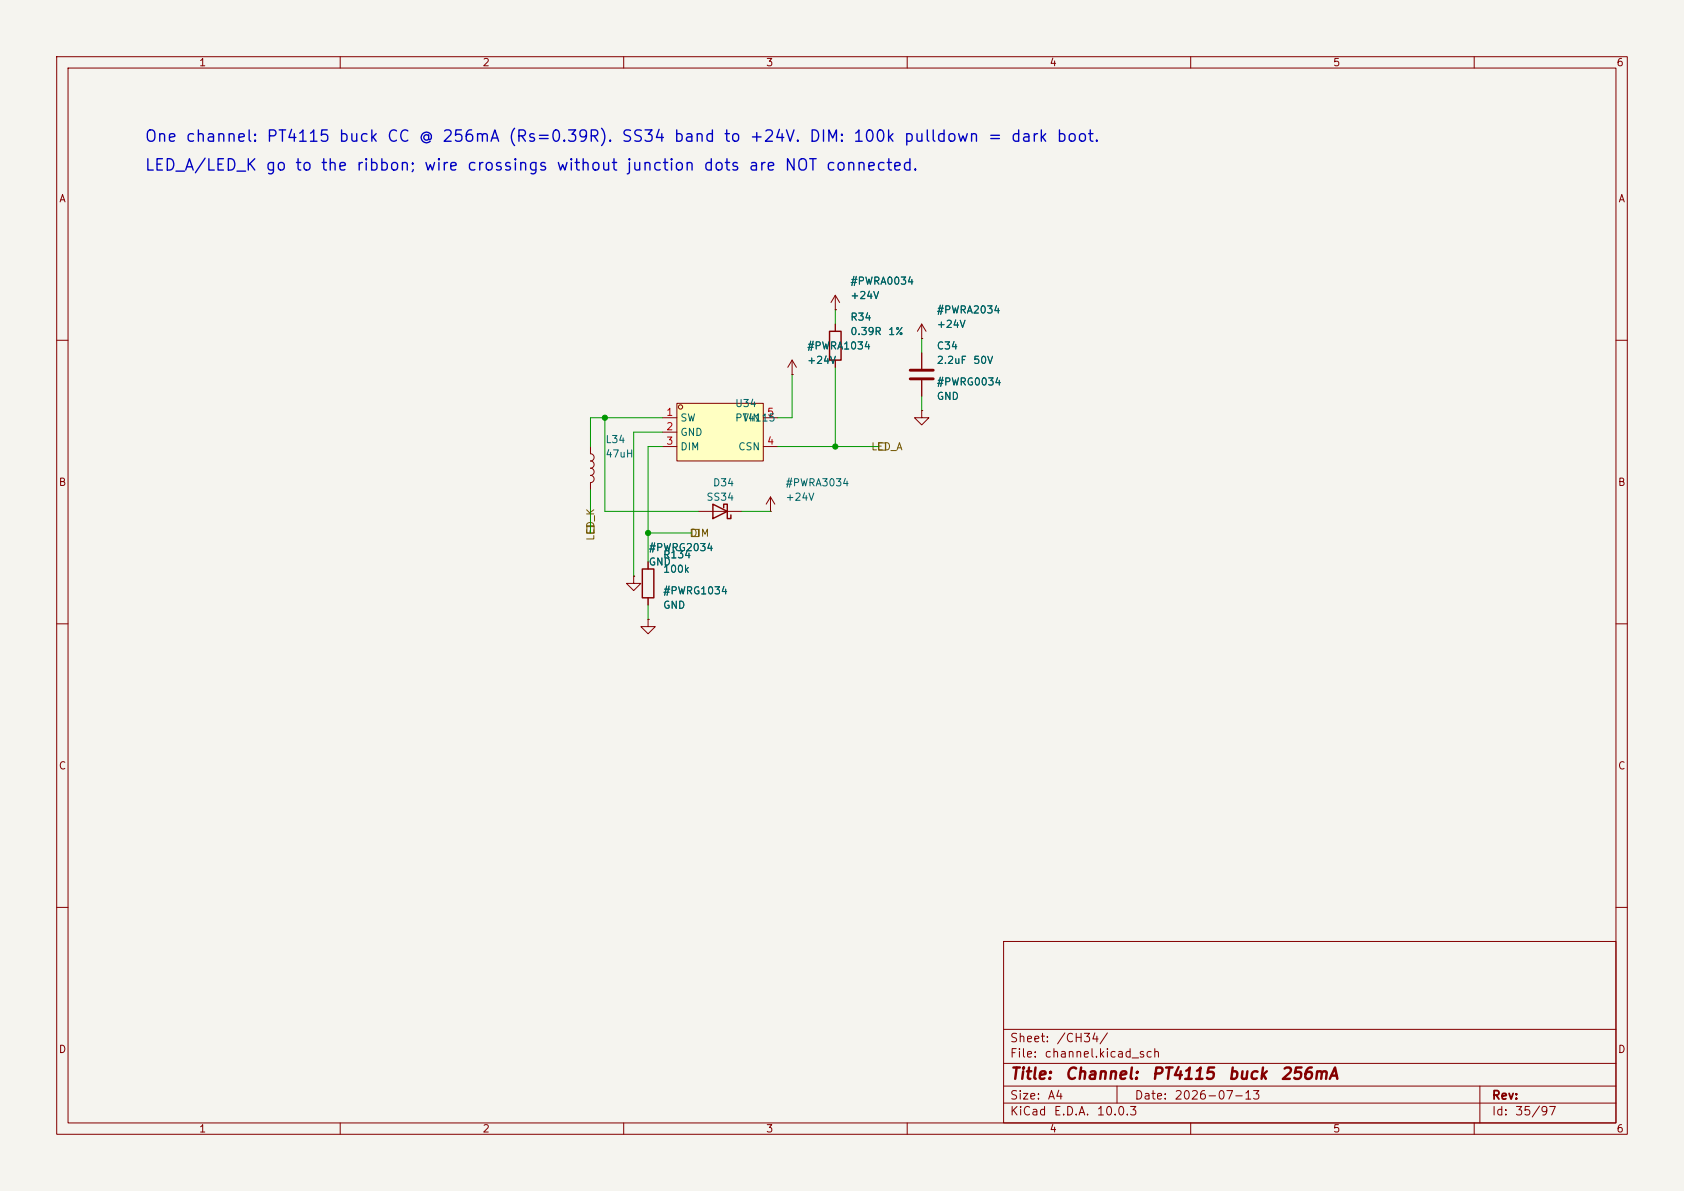
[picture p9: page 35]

One channel: PT4115 buck CC @ 256mA (Rs=0.39R). SS34 band to +24V. DIM: 100k pulldown = dark boot. C34

One channel: PT4115 buck CC @ 256mA (Rs=0.39R). SS34 band to +24V. DIM: 100k pulldown = dark boot. C35

One channel: PT4115 buck CC @ 256mA (Rs=0.39R). SS34 band to +24V. DIM: 100k pulldown = dark boot. C36

One channel: PT4115 buck CC @ 256mA (Rs=0.39R). SS34 band to +24V. DIM: 100k pulldown = dark boot. C37

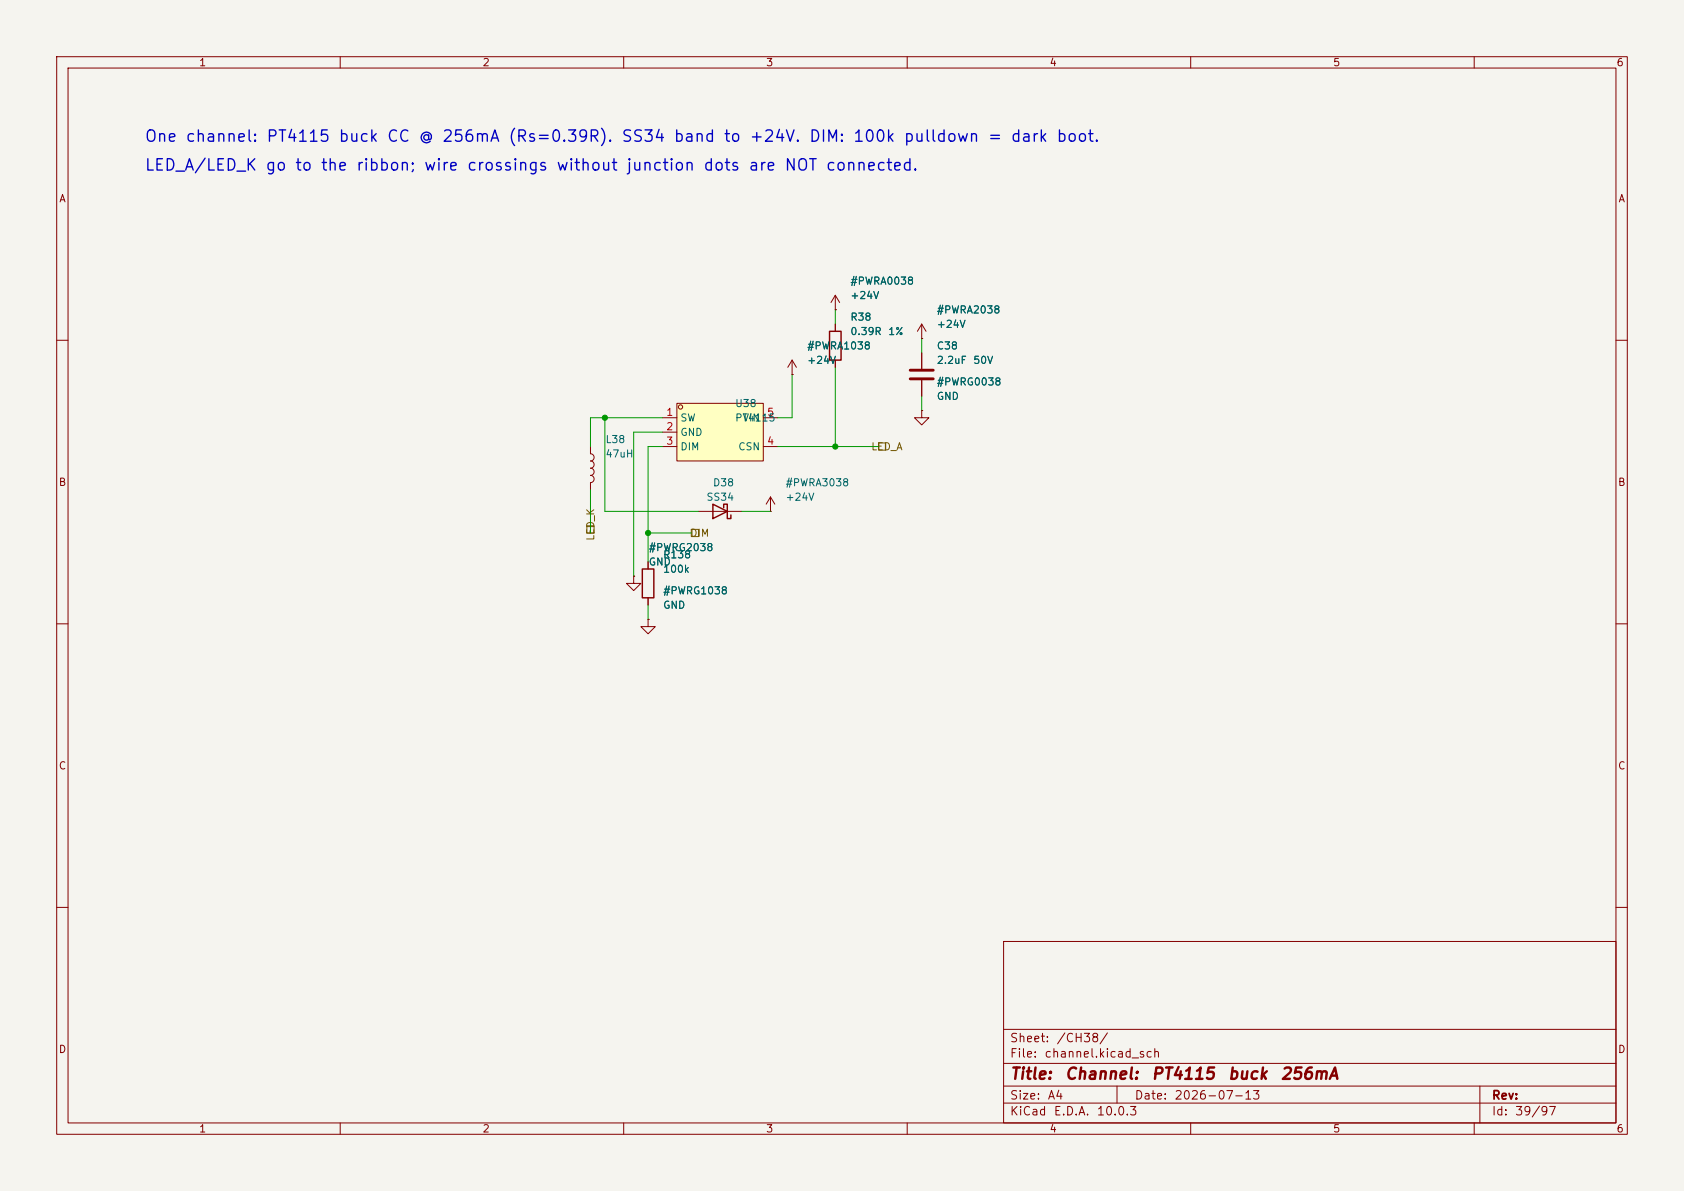
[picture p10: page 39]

One channel: PT4115 buck CC @ 256mA (Rs=0.39R). SS34 band to +24V. DIM: 100k pulldown = dark boot. C38

One channel: PT4115 buck CC @ 256mA (Rs=0.39R). SS34 band to +24V. DIM: 100k pulldown = dark boot. C39
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

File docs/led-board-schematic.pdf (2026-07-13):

RIBBONS TO CONTROL BOARD

LED ch 73-96 COMMONINPUT/OUTPUT 1

LED ch 25-48 COMMONINPUT/OUTPUT 1

Sheet: /
File: 12x8 Led Array 9mm pitch.kicad_sch
Title: 12x8 660nm LED Array - LED Board

Size: A2 | Rev:
KiCad E.D.A. 10.0.3 | Id: 1/97

One well: 660nm LED (pad3 thermal tied to cathode) + 10k NTC / 10k 1% divider from 3V3. TH1 NTC 10k B3434 #PWR011 +3V3 R1
Instantiated 96x from the root sheet (CH01..CH96).

Sheet: /CH01/
File: well.kicad_sch
Title: Well: LED + NTC

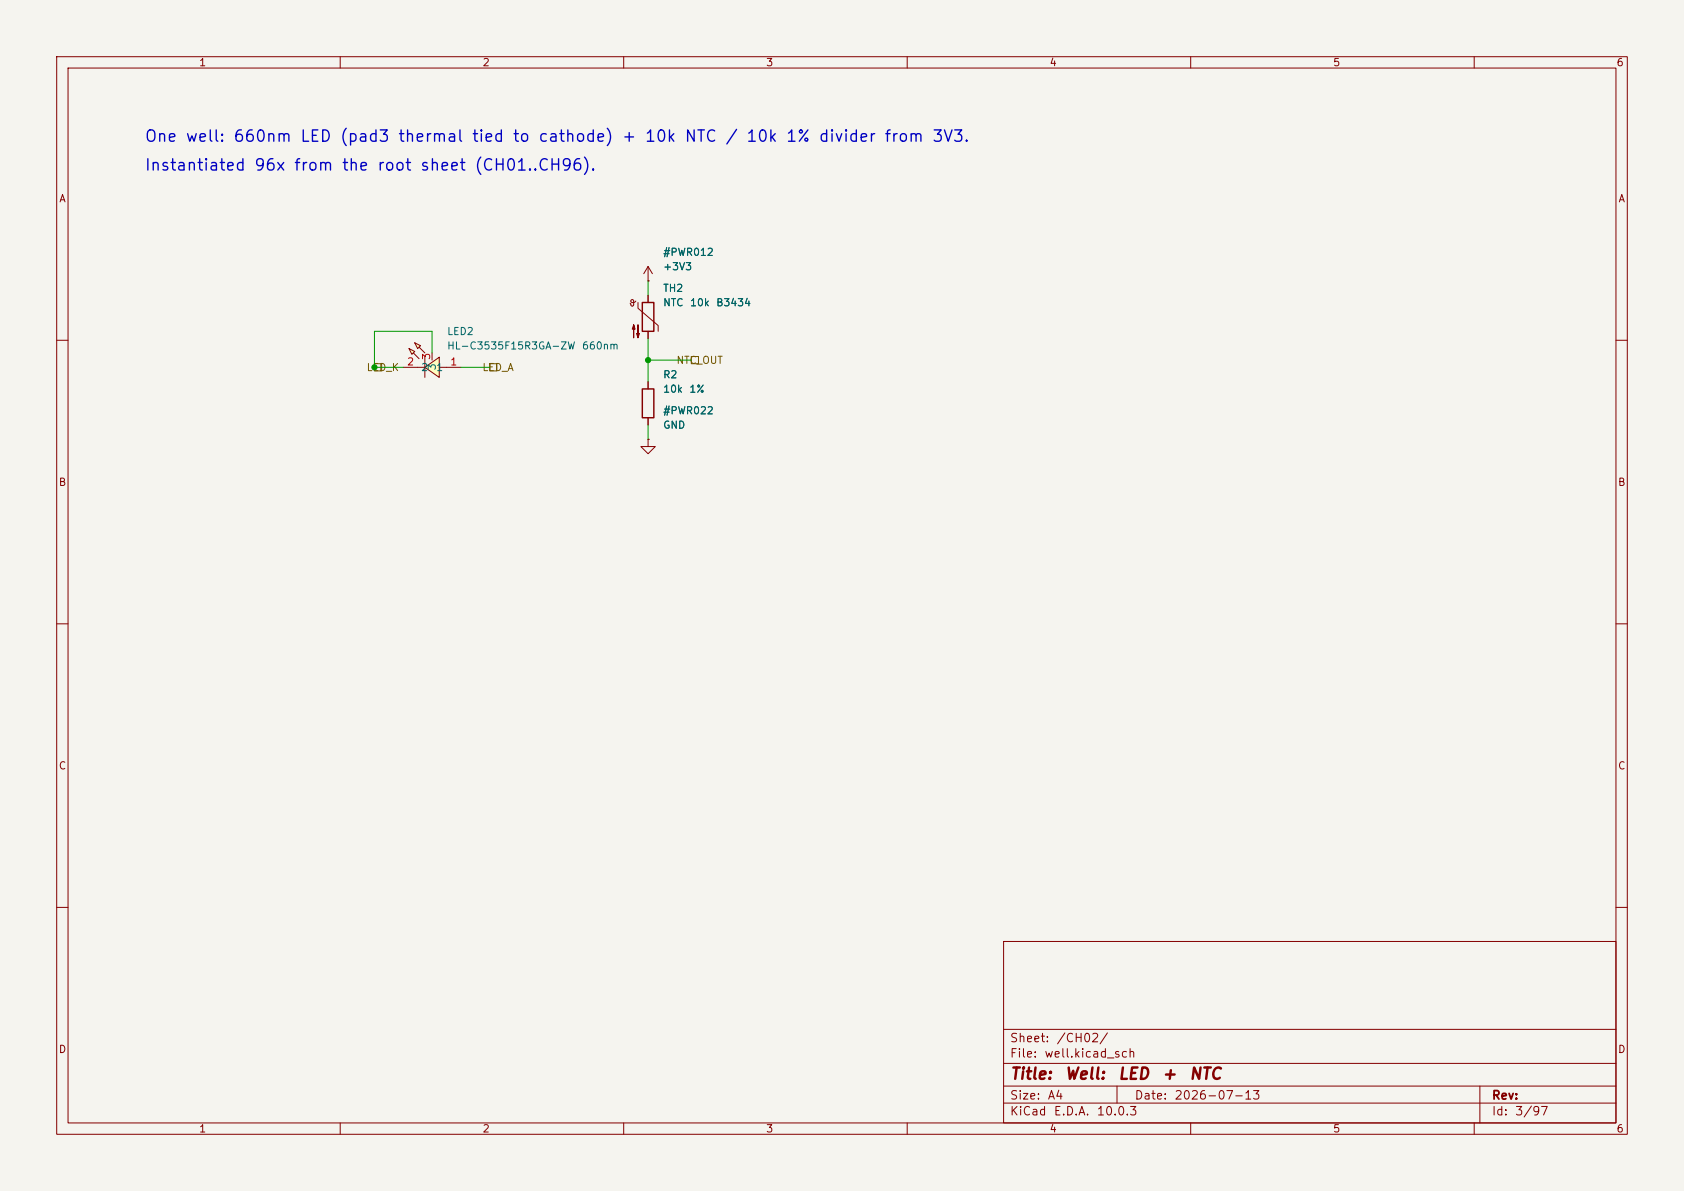
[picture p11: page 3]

One well: 660nm LED (pad3 thermal tied to cathode) + 10k NTC / 10k 1% divider from 3V3.
Instantiated 96x from the root sheet (CH01..CH96).

Sheet: /CH02/
File: well.kicad_sch
Title: Well: LED + NTC

One well: 660nm LED (pad3 thermal tied to cathode) + 10k NTC / 10k 1% divider from 3V3. TH3 NTC 10k B3434 #PWR013 +3V3 R3
Instantiated 96x from the root sheet (CH01..CH96).

Sheet: /CH03/
File: well.kicad_sch
Title: Well: LED + NTC

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

Sheet: /CH04/
File: well.kicad_sch
Title: Well: LED + NTC

One well: 660nm LED (pad3 thermal tied to cathode) + 10k NTC / 10k 1% divider from 3V3. TH5 NTC 10k B3434 #PWR015 +3V3 R5
Instantiated 96x from the root sheet (CH01..CH96).

Sheet: /CH05/
File: well.kicad_sch
Title: Well: LED + NTC

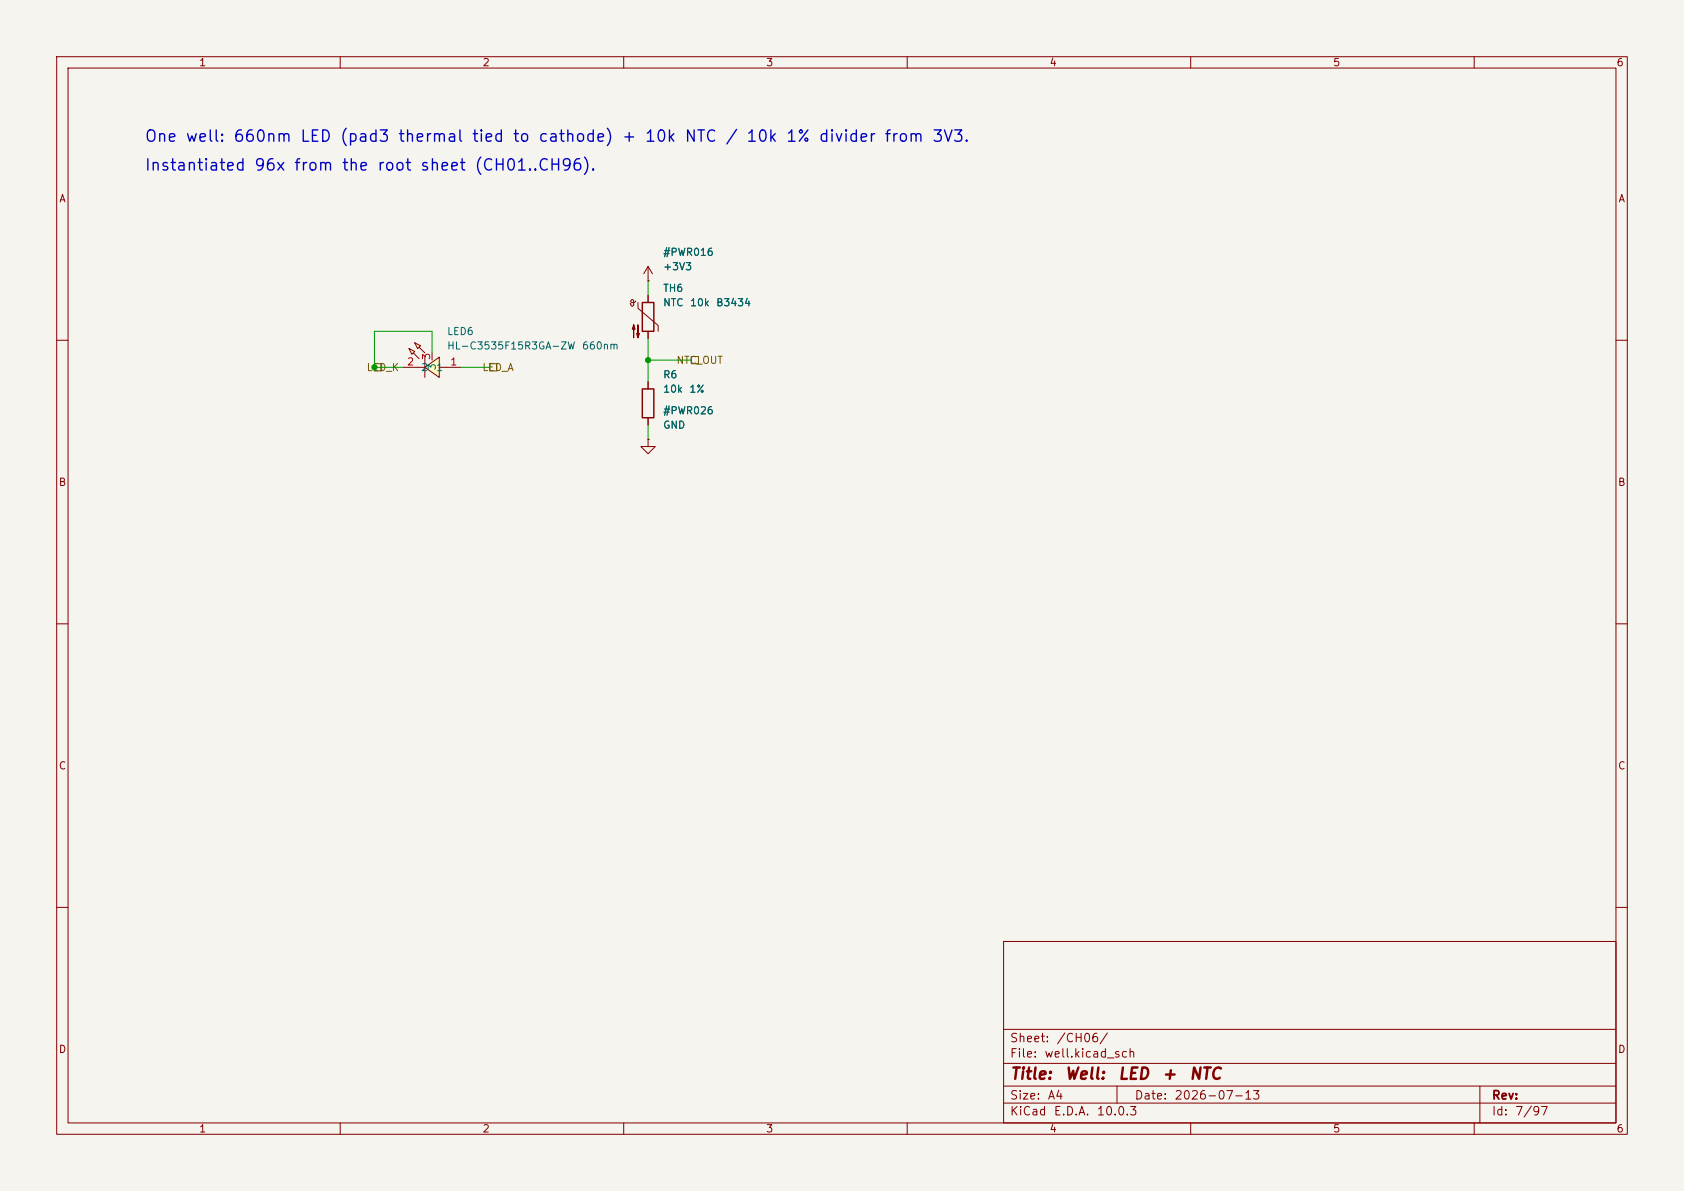
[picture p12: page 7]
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

Sheet: /CH06/
File: well.kicad_sch
Title: Well: LED + NTC

One well: 660nm LED (pad3 thermal tied to cathode) + 10k NTC / 10k 1% divider from 3V3. TH7 NTC 10k B3434 #PWR017 +3V3 R7
Instantiated 96x from the root sheet (CH01..CH96).

Sheet: /CH07/
File: well.kicad_sch
Title: Well: LED + NTC

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

Sheet: /CH08/
File: well.kicad_sch
Title: Well: LED + NTC

One well: 660nm LED (pad3 thermal tied to cathode) + 10k NTC / 10k 1% divider from 3V3. TH9 NTC 10k B3434 #PWR019 +3V3 R9
Instantiated 96x from the root sheet (CH01..CH96).

Sheet: /CH09/
File: well.kicad_sch
Title: Well: LED + NTC

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

Sheet: /CH10/
File: well.kicad_sch
Title: Well: LED + NTC

One well: 660nm LED (pad3 thermal tied to cathode) + 10k NTC / 10k 1% divider from 3V3. TH11 NTC 10k B3434 #PWR0111 +3V3 R11
Instantiated 96x from the root sheet (CH01..CH96).

Sheet: /CH11/
File: well.kicad_sch
Title: Well: LED + NTC

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

Sheet: /CH12/
File: well.kicad_sch
Title: Well: LED + NTC

One well: 660nm LED (pad3 thermal tied to cathode) + 10k NTC / 10k 1% divider from 3V3. TH13 NTC 10k B3434 #PWR0113 +3V3 R13
Instantiated 96x from the root sheet (CH01..CH96).

Sheet: /CH13/
File: well.kicad_sch
Title: Well: LED + NTC

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

Sheet: /CH14/
File: well.kicad_sch
Title: Well: LED + NTC

One well: 660nm LED (pad3 thermal tied to cathode) + 10k NTC / 10k 1% divider from 3V3. TH15 NTC 10k B3434 #PWR0115 +3V3 R15
Instantiated 96x from the root sheet (CH01..CH96).

Sheet: /CH15/
File: well.kicad_sch
Title: Well: LED + NTC

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

Sheet: /CH16/
File: well.kicad_sch
Title: Well: LED + NTC

One well: 660nm LED (pad3 thermal tied to cathode) + 10k NTC / 10k 1% divider from 3V3. TH17 NTC 10k B3434 #PWR0117 +3V3 R17
Instantiated 96x from the root sheet (CH01..CH96).

Sheet: /CH17/
File: well.kicad_sch
Title: Well: LED + NTC

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

Sheet: /CH18/
File: well.kicad_sch
Title: Well: LED + NTC

One well: 660nm LED (pad3 thermal tied to cathode) + 10k NTC / 10k 1% divider from 3V3. TH19 NTC 10k B3434 #PWR0119 +3V3 R19
Instantiated 96x from the root sheet (CH01..CH96).

Sheet: /CH19/
File: well.kicad_sch
Title: Well: LED + NTC
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

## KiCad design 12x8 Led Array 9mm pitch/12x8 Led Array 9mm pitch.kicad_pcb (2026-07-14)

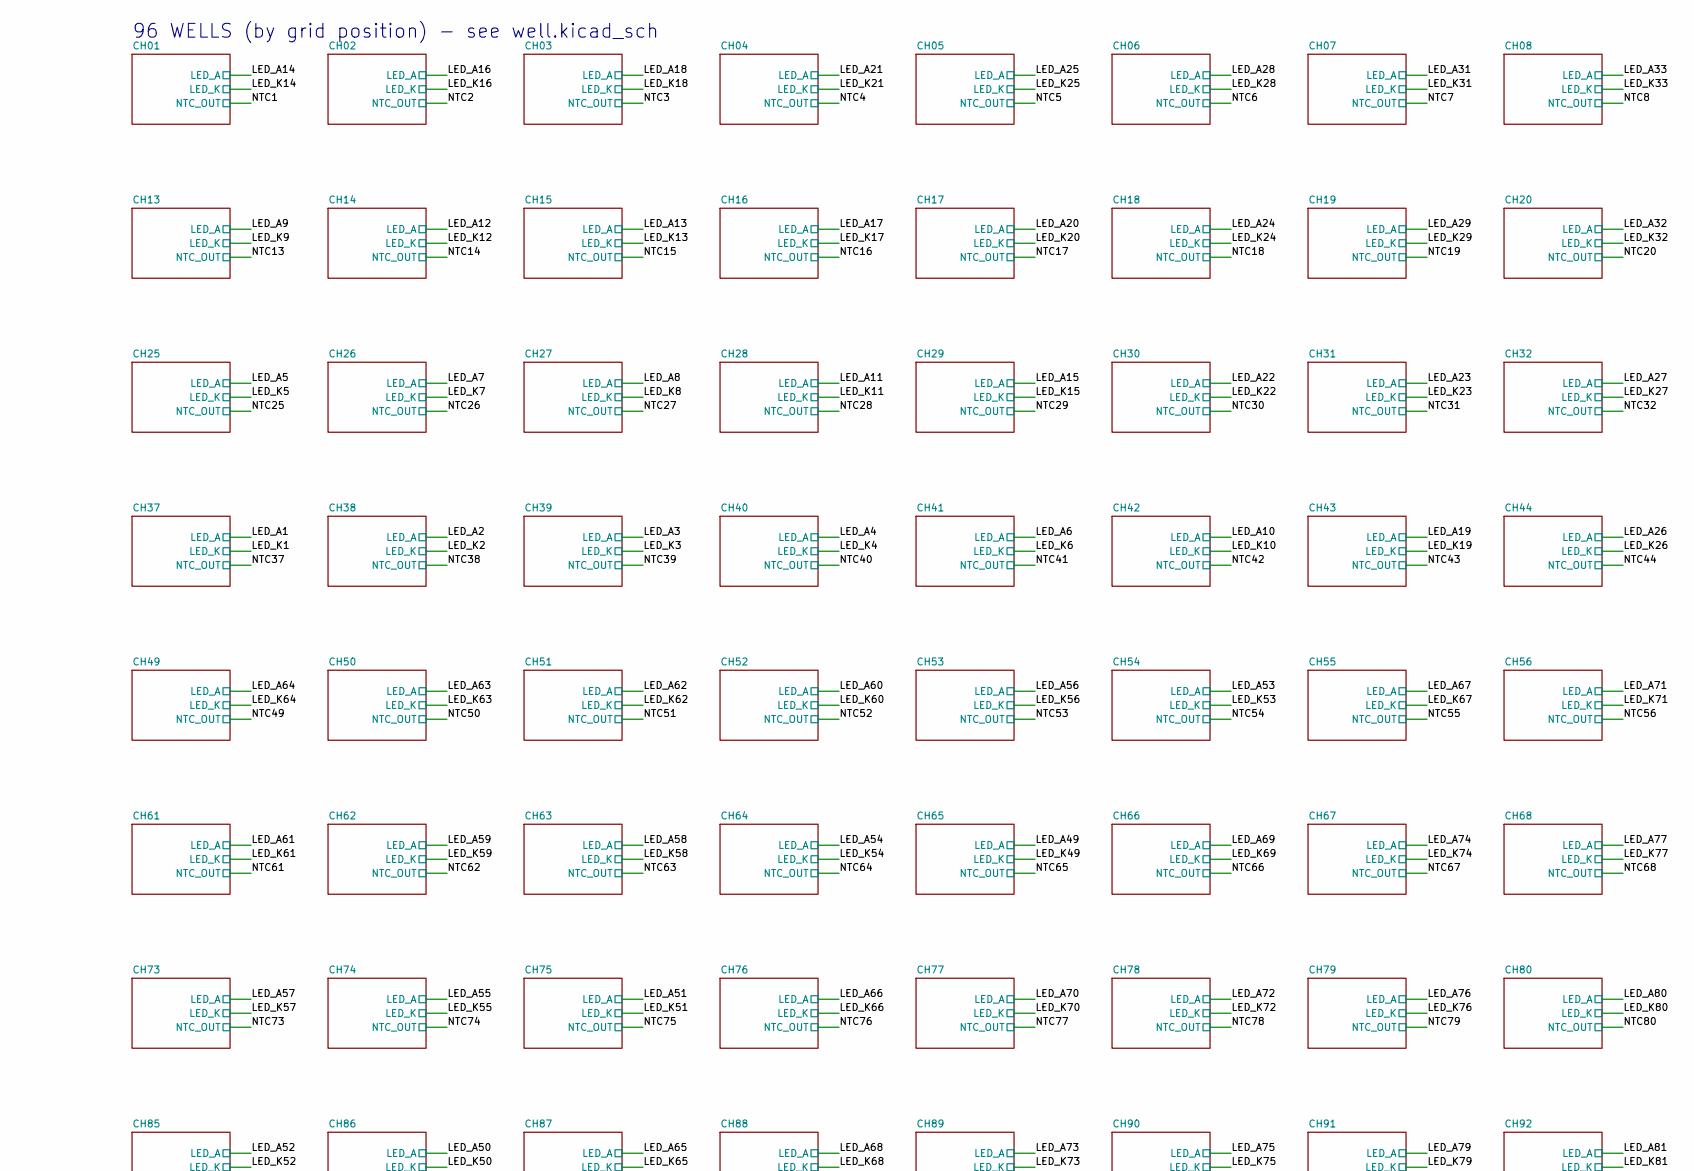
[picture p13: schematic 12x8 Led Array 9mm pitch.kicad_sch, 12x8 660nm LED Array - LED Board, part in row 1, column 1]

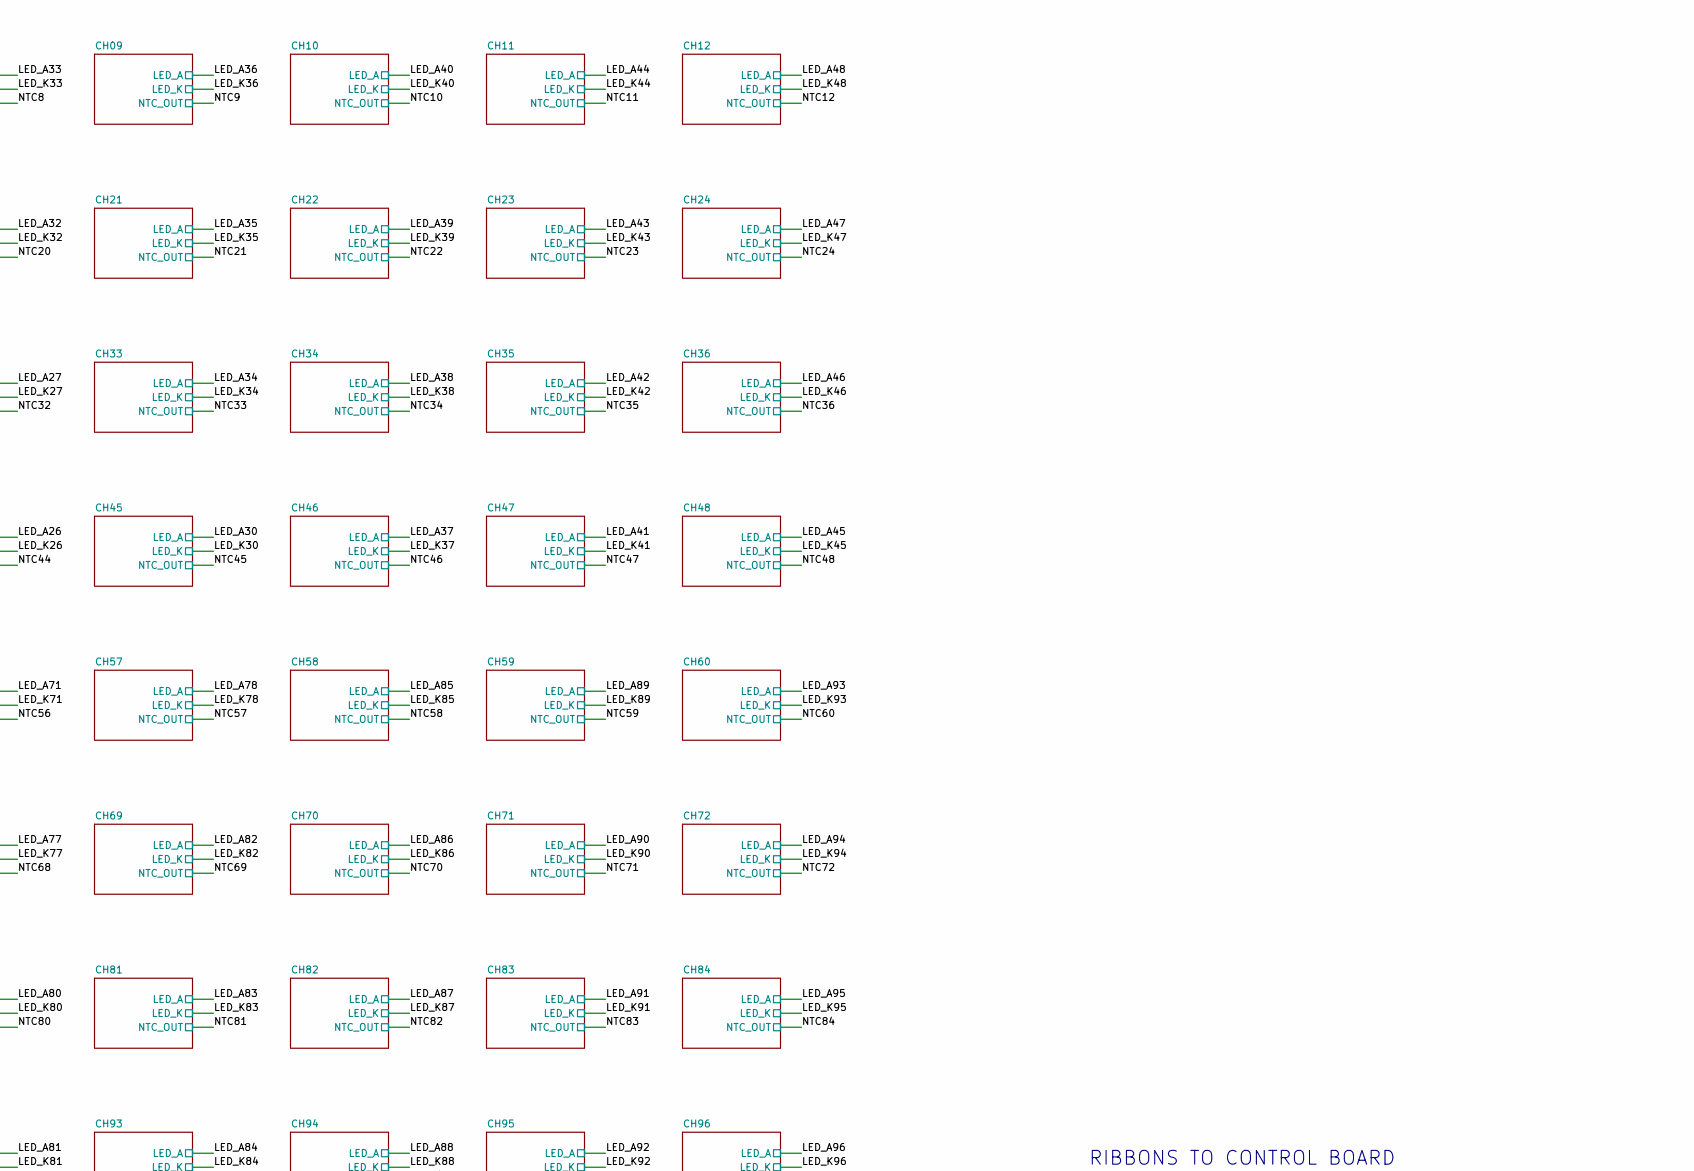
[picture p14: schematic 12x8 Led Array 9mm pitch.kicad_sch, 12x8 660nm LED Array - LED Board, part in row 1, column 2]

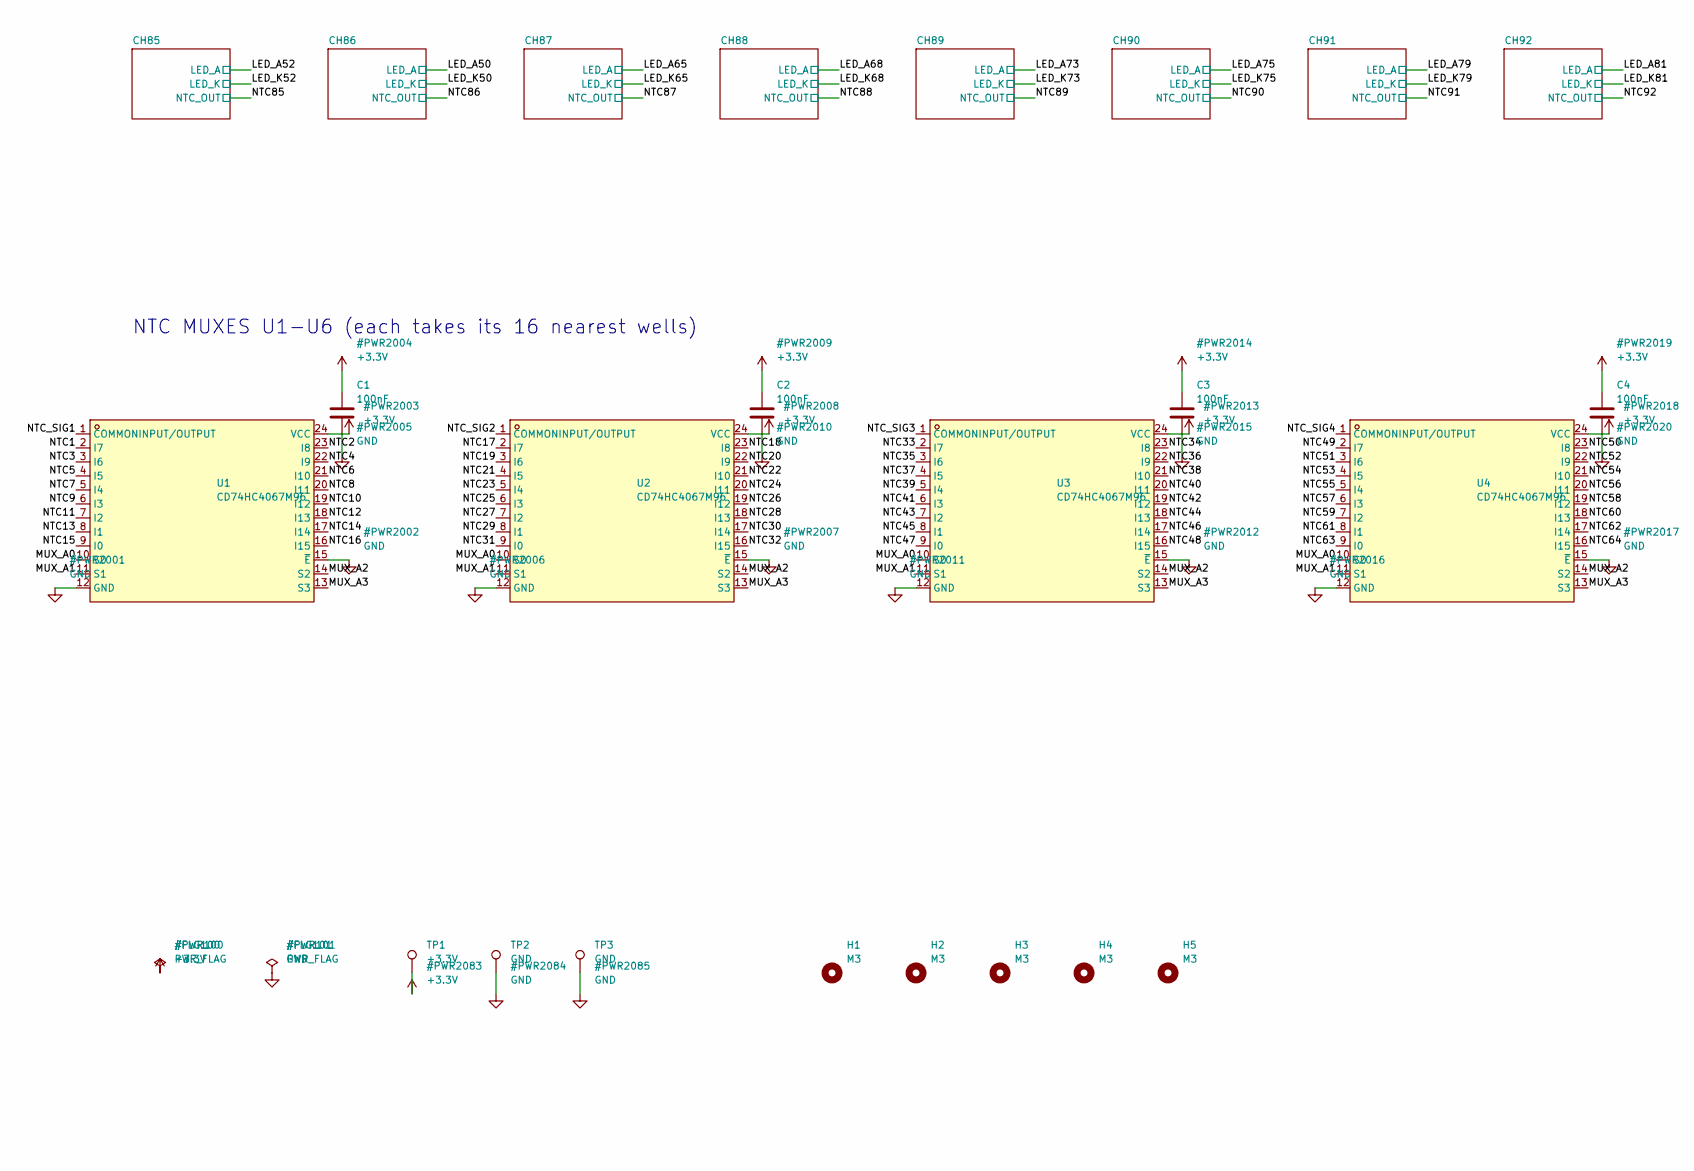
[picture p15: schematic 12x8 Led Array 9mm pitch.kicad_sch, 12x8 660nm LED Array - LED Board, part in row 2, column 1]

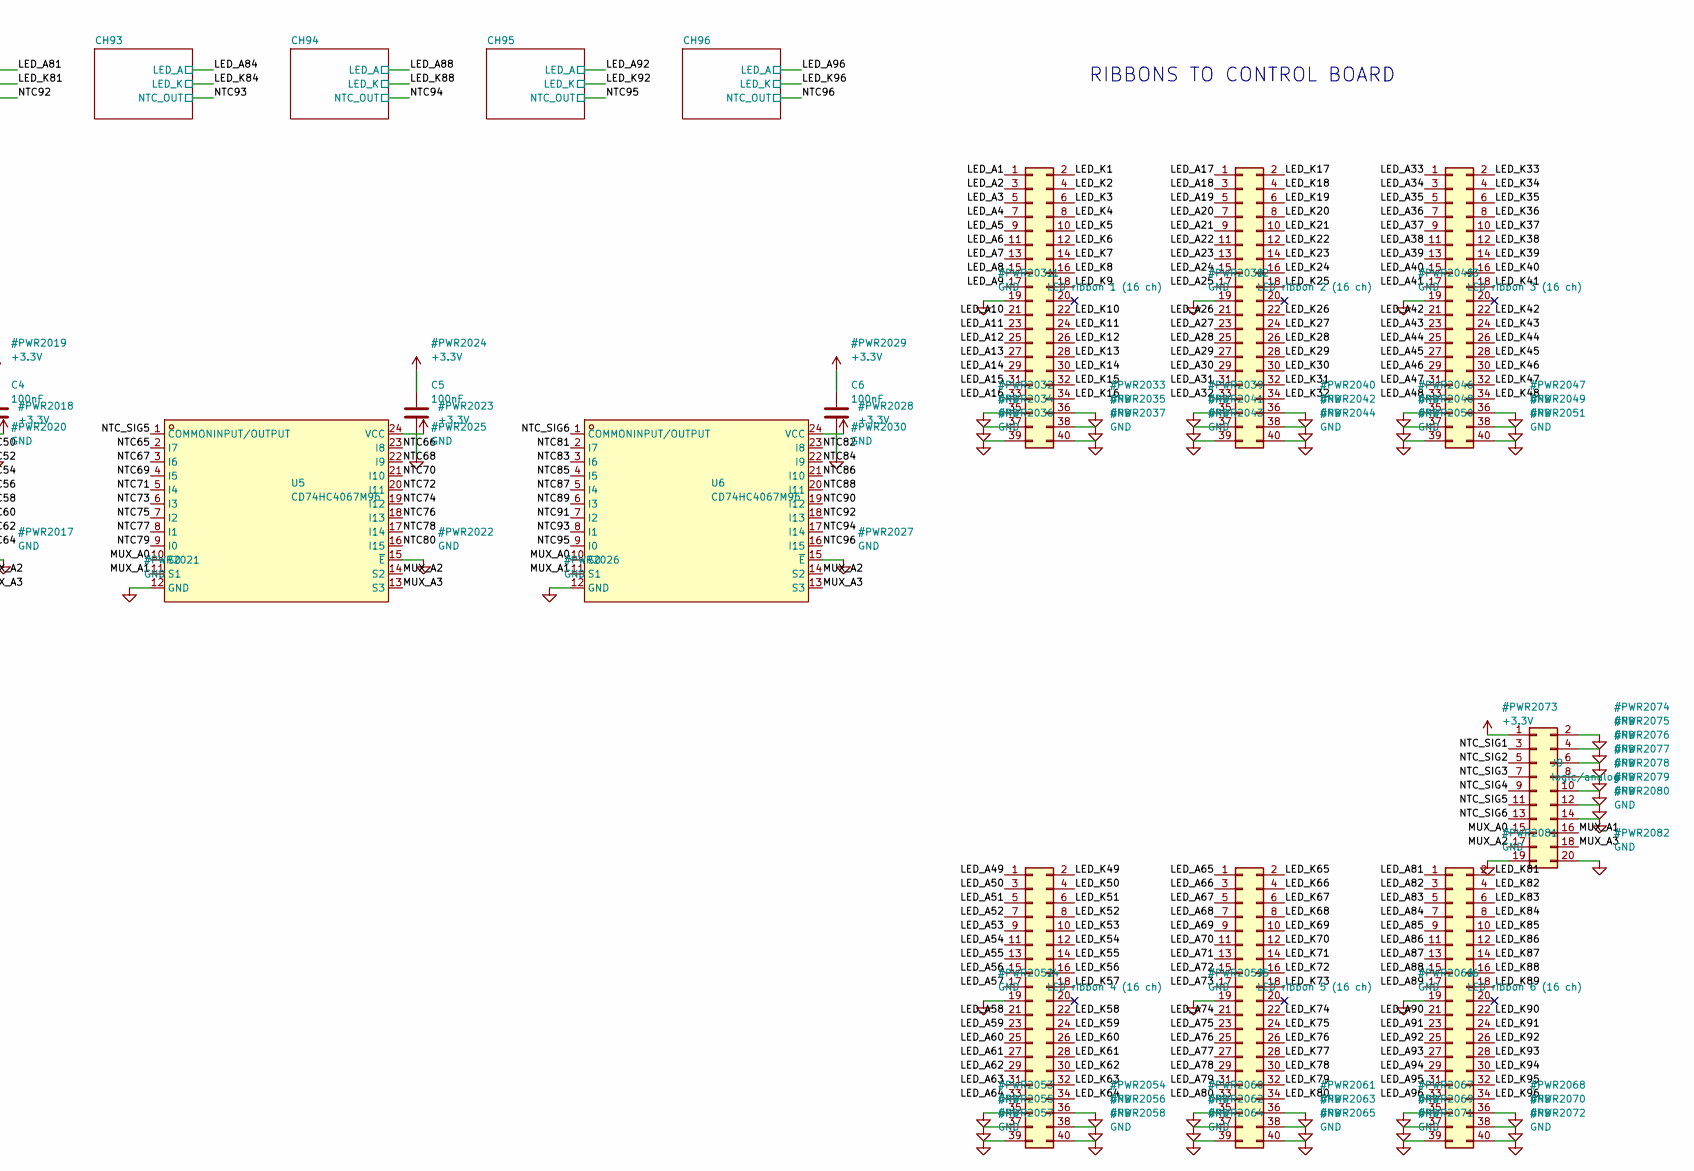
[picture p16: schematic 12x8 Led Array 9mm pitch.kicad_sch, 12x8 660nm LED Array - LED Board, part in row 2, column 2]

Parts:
C1, C2, C3, C4, C5, C6: 100nF; C_0603_1608Metric; LCSC C14663
H1, H2, H3, H4, H5: M3; MountingHole_3.2mm_M3
J1: LED ribbon 1 (16 ch); IDC-Header_2x20_P2.54mm_Vertical; LCSC C9043
J2: LED ribbon 2 (16 ch); IDC-Header_2x20_P2.54mm_Vertical; LCSC C9043
J3: LED ribbon 3 (16 ch); IDC-Header_2x20_P2.54mm_Vertical; LCSC C9043
J4: LED ribbon 4 (16 ch); IDC-Header_2x20_P2.54mm_Vertical; LCSC C9043
J5: LED ribbon 5 (16 ch); IDC-Header_2x20_P2.54mm_Vertical; LCSC C9043
J6: LED ribbon 6 (16 ch); IDC-Header_2x20_P2.54mm_Vertical; LCSC C9043
J9: logic/analog; IDC-Header_2x10_P2.54mm_Horizontal; LCSC C9144
TP1: +3.3V; TestPoint_Pad_1.5x1.5mm
TP2, TP3: GND; TestPoint_Pad_1.5x1.5mm
U1, U2, U3, U4, U5, U6: CD74HC4067M96; SOIC-24_L15.4-W7.5-P1.27-LS10.3-BL; LCSC C496123

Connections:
+3.3V: C1.1, C2.1, C3.1, C4.1, C5.1, C6.1, J9.1, TP1.1 (1_1), U1.24 (VCC), U2.24 (VCC), U3.24 (VCC), U4.24 (VCC), U5.24 (VCC), U6.24 (VCC); also elsewhere on the board
/LED_A1: J1.1; also elsewhere on the board
/LED_A2: J1.3; also elsewhere on the board
/LED_A3: J1.5; also elsewhere on the board
/LED_A4: J1.7; also elsewhere on the board
/LED_A5: J1.9; also elsewhere on the board
/LED_A6: J1.11; also elsewhere on the board
/LED_A7: J1.13; also elsewhere on the board
/LED_A8: J1.15; also elsewhere on the board
/LED_A9: J1.17; also elsewhere on the board
/LED_A10: J1.21; also elsewhere on the board
/LED_A11: J1.23; also elsewhere on the board
/LED_A12: J1.25; also elsewhere on the board
/LED_A13: J1.27; also elsewhere on the board
/LED_A14: J1.29; also elsewhere on the board
/LED_A15: J1.31; also elsewhere on the board
/LED_A16: J1.33; also elsewhere on the board
/LED_A17: J2.1; also elsewhere on the board
/LED_A18: J2.3; also elsewhere on the board
/LED_A19: J2.5; also elsewhere on the board
/LED_A20: J2.7; also elsewhere on the board
/LED_A21: J2.9; also elsewhere on the board
/LED_A22: J2.11; also elsewhere on the board
/LED_A23: J2.13; also elsewhere on the board
/LED_A24: J2.15; also elsewhere on the board
/LED_A25: J2.17; also elsewhere on the board
/LED_A26: J2.21; also elsewhere on the board
/LED_A27: J2.23; also elsewhere on the board
/LED_A28: J2.25; also elsewhere on the board
/LED_A29: J2.27; also elsewhere on the board
/LED_A30: J2.29; also elsewhere on the board
/LED_A31: J2.31; also elsewhere on the board
/LED_A32: J2.33; also elsewhere on the board
/LED_A33: J3.1; also elsewhere on the board
/LED_A34: J3.3; also elsewhere on the board
/LED_A35: J3.5; also elsewhere on the board
/LED_A36: J3.7; also elsewhere on the board
/LED_A37: J3.9; also elsewhere on the board
/LED_A38: J3.11; also elsewhere on the board
/LED_A39: J3.13; also elsewhere on the board
/LED_A40: J3.15; also elsewhere on the board
/LED_A41: J3.17; also elsewhere on the board
/LED_A42: J3.21; also elsewhere on the board
/LED_A43: J3.23; also elsewhere on the board
/LED_A44: J3.25; also elsewhere on the board
/LED_A45: J3.27; also elsewhere on the board
/LED_A46: J3.29; also elsewhere on the board
/LED_A47: J3.31; also elsewhere on the board
/LED_A48: J3.33; also elsewhere on the board
/LED_A49: J4.1; also elsewhere on the board
/LED_A50: J4.3; also elsewhere on the board
/LED_A51: J4.5; also elsewhere on the board
/LED_A52: J4.7; also elsewhere on the board
/LED_A53: J4.9; also elsewhere on the board
/LED_A54: J4.11; also elsewhere on the board
/LED_A55: J4.13; also elsewhere on the board
/LED_A56: J4.15; also elsewhere on the board
/LED_A57: J4.17; also elsewhere on the board
/LED_A58: J4.21; also elsewhere on the board
/LED_A59: J4.23; also elsewhere on the board
/LED_A60: J4.25; also elsewhere on the board
/LED_A61: J4.27; also elsewhere on the board
/LED_A62: J4.29; also elsewhere on the board
/LED_A63: J4.31; also elsewhere on the board
/LED_A64: J4.33; also elsewhere on the board
/LED_A65: J5.1; also elsewhere on the board
/LED_A66: J5.3; also elsewhere on the board
/LED_A67: J5.5; also elsewhere on the board
/LED_A68: J5.7; also elsewhere on the board
/LED_A69: J5.9; also elsewhere on the board
/LED_A70: J5.11; also elsewhere on the board
/LED_A71: J5.13; also elsewhere on the board
/LED_A72: J5.15; also elsewhere on the board
/LED_A73: J5.17; also elsewhere on the board
/LED_A74: J5.21; also elsewhere on the board
/LED_A75: J5.23; also elsewhere on the board
/LED_A76: J5.25; also elsewhere on the board
/LED_A77: J5.27; also elsewhere on the board
/LED_A78: J5.29; also elsewhere on the board
/LED_A79: J5.31; also elsewhere on the board
/LED_A80: J5.33; also elsewhere on the board
/LED_A81: J6.1; also elsewhere on the board
/LED_A82: J6.3; also elsewhere on the board
/LED_A83: J6.5; also elsewhere on the board
/LED_A84: J6.7; also elsewhere on the board
/LED_A85: J6.9; also elsewhere on the board
/LED_A86: J6.11; also elsewhere on the board
/LED_A87: J6.13; also elsewhere on the board
/LED_A88: J6.15; also elsewhere on the board
/LED_A89: J6.17; also elsewhere on the board
/LED_A90: J6.21; also elsewhere on the board
/LED_A91: J6.23; also elsewhere on the board
/LED_A92: J6.25; also elsewhere on the board
/LED_A93: J6.27; also elsewhere on the board
/LED_A94: J6.29; also elsewhere on the board
/LED_A95: J6.31; also elsewhere on the board
/LED_A96: J6.33; also elsewhere on the board
/LED_K1: J1.2; also elsewhere on the board
/LED_K2: J1.4; also elsewhere on the board
/LED_K3: J1.6; also elsewhere on the board
/LED_K4: J1.8; also elsewhere on the board
/LED_K5: J1.10; also elsewhere on the board
/LED_K6: J1.12; also elsewhere on the board
/LED_K7: J1.14; also elsewhere on the board
/LED_K8: J1.16; also elsewhere on the board
/LED_K9: J1.18; also elsewhere on the board
/LED_K10: J1.22; also elsewhere on the board
/LED_K11: J1.24; also elsewhere on the board
/LED_K12: J1.26; also elsewhere on the board
/LED_K13: J1.28; also elsewhere on the board
/LED_K14: J1.30; also elsewhere on the board
/LED_K15: J1.32; also elsewhere on the board
/LED_K16: J1.34; also elsewhere on the board
/LED_K17: J2.2; also elsewhere on the board
/LED_K18: J2.4; also elsewhere on the board
/LED_K19: J2.6; also elsewhere on the board
/LED_K20: J2.8; also elsewhere on the board
/LED_K21: J2.10; also elsewhere on the board
/LED_K22: J2.12; also elsewhere on the board
/LED_K23: J2.14; also elsewhere on the board
/LED_K24: J2.16; also elsewhere on the board
/LED_K25: J2.18; also elsewhere on the board
/LED_K26: J2.22; also elsewhere on the board
/LED_K27: J2.24; also elsewhere on the board
/LED_K28: J2.26; also elsewhere on the board
/LED_K29: J2.28; also elsewhere on the board
/LED_K30: J2.30; also elsewhere on the board
/LED_K31: J2.32; also elsewhere on the board
/LED_K32: J2.34; also elsewhere on the board
/LED_K33: J3.2; also elsewhere on the board
/LED_K34: J3.4; also elsewhere on the board
/LED_K35: J3.6; also elsewhere on the board
/LED_K36: J3.8; also elsewhere on the board
/LED_K37: J3.10; also elsewhere on the board
/LED_K38: J3.12; also elsewhere on the board
/LED_K39: J3.14; also elsewhere on the board
/LED_K40: J3.16; also elsewhere on the board
/LED_K41: J3.18; also elsewhere on the board
/LED_K42: J3.22; also elsewhere on the board
/LED_K43: J3.24; also elsewhere on the board
/LED_K44: J3.26; also elsewhere on the board
/LED_K45: J3.28; also elsewhere on the board
/LED_K46: J3.30; also elsewhere on the board
/LED_K47: J3.32; also elsewhere on the board
/LED_K48: J3.34; also elsewhere on the board
/LED_K49: J4.2; also elsewhere on the board
/LED_K50: J4.4; also elsewhere on the board
/LED_K51: J4.6; also elsewhere on the board
/LED_K52: J4.8; also elsewhere on the board
/LED_K53: J4.10; also elsewhere on the board
/LED_K54: J4.12; also elsewhere on the board
/LED_K55: J4.14; also elsewhere on the board
/LED_K56: J4.16; also elsewhere on the board
/LED_K57: J4.18; also elsewhere on the board
/LED_K58: J4.22; also elsewhere on the board
/LED_K59: J4.24; also elsewhere on the board
/LED_K60: J4.26; also elsewhere on the board
/LED_K61: J4.28; also elsewhere on the board
/LED_K62: J4.30; also elsewhere on the board
/LED_K63: J4.32; also elsewhere on the board
/LED_K64: J4.34; also elsewhere on the board
/LED_K65: J5.2; also elsewhere on the board
/LED_K66: J5.4; also elsewhere on the board
/LED_K67: J5.6; also elsewhere on the board
/LED_K68: J5.8; also elsewhere on the board
/LED_K69: J5.10; also elsewhere on the board
/LED_K70: J5.12; also elsewhere on the board
/LED_K71: J5.14; also elsewhere on the board
/LED_K72: J5.16; also elsewhere on the board
/LED_K73: J5.18; also elsewhere on the board
/LED_K74: J5.22; also elsewhere on the board
/LED_K75: J5.24; also elsewhere on the board
/LED_K76: J5.26; also elsewhere on the board
/LED_K77: J5.28; also elsewhere on the board
/LED_K78: J5.30; also elsewhere on the board
/LED_K79: J5.32; also elsewhere on the board
/LED_K80: J5.34; also elsewhere on the board
/LED_K81: J6.2; also elsewhere on the board
/LED_K82: J6.4; also elsewhere on the board
/LED_K83: J6.6; also elsewhere on the board
/LED_K84: J6.8; also elsewhere on the board
/LED_K85: J6.10; also elsewhere on the board
/LED_K86: J6.12; also elsewhere on the board
/LED_K87: J6.14; also elsewhere on the board
/LED_K88: J6.16; also elsewhere on the board
/LED_K89: J6.18; also elsewhere on the board
/LED_K90: J6.22; also elsewhere on the board
/LED_K91: J6.24; also elsewhere on the board
/LED_K92: J6.26; also elsewhere on the board
/LED_K93: J6.28; also elsewhere on the board
/LED_K94: J6.30; also elsewhere on the board
/LED_K95: J6.32; also elsewhere on the board
/LED_K96: J6.34; also elsewhere on the board
/MUX_A0: J9.15, U1.10 (S0), U2.10 (S0), U3.10 (S0), U4.10 (S0), U5.10 (S0), U6.10 (S0)
/MUX_A1: J9.16, U1.11 (S1), U2.11 (S1), U3.11 (S1), U4.11 (S1), U5.11 (S1), U6.11 (S1)
/MUX_A2: J9.17, U1.14 (S2), U2.14 (S2), U3.14 (S2), U4.14 (S2), U5.14 (S2), U6.14 (S2)
/MUX_A3: J9.18, U1.13 (S3), U2.13 (S3), U3.13 (S3), U4.13 (S3), U5.13 (S3), U6.13 (S3)
/NTC1: U1.2 (I7); also elsewhere on the board
/NTC2: U1.23 (I8); also elsewhere on the board
/NTC3: U1.3 (I6); also elsewhere on the board
/NTC4: U1.22 (I9); also elsewhere on the board
/NTC5: U1.4 (I5); also elsewhere on the board
/NTC6: U1.21 (I10); also elsewhere on the board
/NTC7: U1.5 (I4); also elsewhere on the board
/NTC8: U1.20 (I11); also elsewhere on the board
/NTC9: U1.6 (I3); also elsewhere on the board
/NTC10: U1.19 (I12); also elsewhere on the board
/NTC11: U1.7 (I2); also elsewhere on the board
/NTC12: U1.18 (I13); also elsewhere on the board
/NTC13: U1.8 (I1); also elsewhere on the board
/NTC14: U1.17 (I14); also elsewhere on the board
/NTC15: U1.9 (I0); also elsewhere on the board
/NTC16: U1.16 (I15); also elsewhere on the board
/NTC17: U2.2 (I7); also elsewhere on the board
/NTC18: U2.23 (I8); also elsewhere on the board
/NTC19: U2.3 (I6); also elsewhere on the board
/NTC20: U2.22 (I9); also elsewhere on the board
/NTC21: U2.4 (I5); also elsewhere on the board
/NTC22: U2.21 (I10); also elsewhere on the board
/NTC23: U2.5 (I4); also elsewhere on the board
/NTC24: U2.20 (I11); also elsewhere on the board
/NTC25: U2.6 (I3); also elsewhere on the board
/NTC26: U2.19 (I12); also elsewhere on the board
/NTC27: U2.7 (I2); also elsewhere on the board
/NTC28: U2.18 (I13); also elsewhere on the board
/NTC29: U2.8 (I1); also elsewhere on the board
/NTC30: U2.17 (I14); also elsewhere on the board
/NTC31: U2.9 (I0); also elsewhere on the board
/NTC32: U2.16 (I15); also elsewhere on the board
/NTC33: U3.2 (I7); also elsewhere on the board
/NTC34: U3.23 (I8); also elsewhere on the board
/NTC35: U3.3 (I6); also elsewhere on the board
/NTC36: U3.22 (I9); also elsewhere on the board
/NTC37: U3.4 (I5); also elsewhere on the board
/NTC38: U3.21 (I10); also elsewhere on the board
/NTC39: U3.5 (I4); also elsewhere on the board
/NTC40: U3.20 (I11); also elsewhere on the board
/NTC41: U3.6 (I3); also elsewhere on the board
/NTC42: U3.19 (I12); also elsewhere on the board
/NTC43: U3.7 (I2); also elsewhere on the board
/NTC44: U3.18 (I13); also elsewhere on the board
/NTC45: U3.8 (I1); also elsewhere on the board
/NTC46: U3.17 (I14); also elsewhere on the board
/NTC47: U3.9 (I0); also elsewhere on the board
/NTC48: U3.16 (I15); also elsewhere on the board
/NTC49: U4.2 (I7); also elsewhere on the board
/NTC50: U4.23 (I8); also elsewhere on the board
/NTC51: U4.3 (I6); also elsewhere on the board
/NTC52: U4.22 (I9); also elsewhere on the board
/NTC53: U4.4 (I5); also elsewhere on the board
/NTC54: U4.21 (I10); also elsewhere on the board
/NTC55: U4.5 (I4); also elsewhere on the board
/NTC56: U4.20 (I11); also elsewhere on the board
/NTC57: U4.6 (I3); also elsewhere on the board
/NTC58: U4.19 (I12); also elsewhere on the board
/NTC59: U4.7 (I2); also elsewhere on the board
/NTC60: U4.18 (I13); also elsewhere on the board
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

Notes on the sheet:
96 WELLS (by grid position) - see well.kicad_sch
NTC MUXES U1-U6 (each takes its 16 nearest wells)
RIBBONS TO CONTROL BOARD

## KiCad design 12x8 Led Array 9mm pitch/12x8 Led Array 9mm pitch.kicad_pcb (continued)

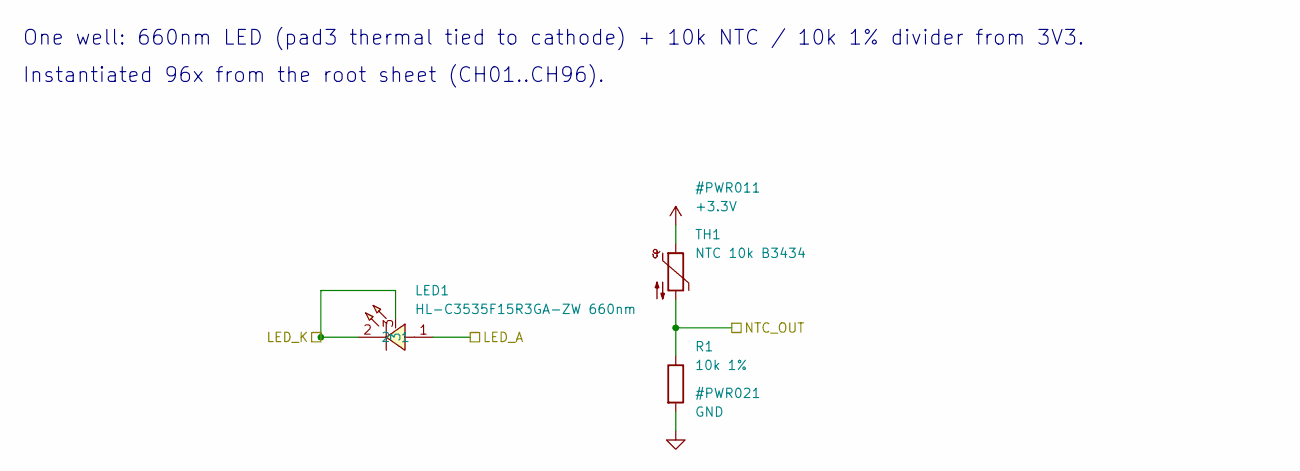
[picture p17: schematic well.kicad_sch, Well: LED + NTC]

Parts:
LED1: HL-C3535F15R3GA-ZW 660nm; LED-SMD_3P-L3.5-W3.5_NLW3535AV2; LCSC C5445086
R1: 10k 1%; R_0603_1608Metric; LCSC C25804
TH1: NTC 10k B3434; R_0603_1608Metric; LCSC C13564

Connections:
+3.3V: TH1.1; also elsewhere on the board
/LED_A14: LED1.1; also elsewhere on the board
/LED_K14: LED1.2, LED1.3; also elsewhere on the board
/NTC1: R1.1, TH1.2; also elsewhere on the board
GND: R1.2; also elsewhere on the board

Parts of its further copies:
LED2, LED3, LED4, LED5, LED6, LED7, LED8, LED9, LED10, LED11, LED12, LED13, LED14, LED15, LED16, LED17, LED18, LED19, LED20, LED21, LED22, LED23, LED24, LED25, LED26, LED27, LED28, LED29, LED30, LED31, LED32, LED33, LED34, LED35, LED36, LED37, LED38, LED39, LED40, LED41, LED42, LED43, LED44, LED45, LED46, LED47, LED48, LED49, LED50, LED51, LED52, LED53, LED54, LED55, LED56, LED57, LED58, LED59, LED60, LED61, LED62, LED63, LED64, LED65, LED66, LED67, LED68, LED69, LED70, LED71, LED72, LED73, LED74, LED75, LED76, LED77, LED78, LED79, LED80, LED81, LED82, LED83, LED84, LED85, LED86, LED87, LED88, LED89, LED90, LED91, LED92, LED93, LED94, LED95, LED96: HL-C3535F15R3GA-ZW 660nm; LED-SMD_3P-L3.5-W3.5_NLW3535AV2; LCSC C5445086
R2, R3, R4, R5, R6, R7, R8, R9, R10, R11, R12, R13, R14, R15, R16, R17, R18, R19, R20, R21, R22, R23, R24, R25, R26, R27, R28, R29, R30, R31, R32, R33, R34, R35, R36, R37, R38, R39, R40, R41, R42, R43, R44, R45, R46, R47, R48, R49, R50, R51, R52, R53, R54, R55, R56, R57, R58, R59, R60, R61, R62, R63, R64, R65, R66, R67, R68, R69, R70, R71, R72, R73, R74, R75, R76, R77, R78, R79, R80, R81, R82, R83, R84, R85, R86, R87, R88, R89, R90, R91, R92, R93, R94, R95, R96: 10k 1%; R_0603_1608Metric; LCSC C25804
TH2, TH3, TH4, TH5, TH6, TH7, TH8, TH9, TH10, TH11, TH12, TH13, TH14, TH15, TH16, TH17, TH18, TH19, TH20, TH21, TH22, TH23, TH24, TH25, TH26, TH27, TH28, TH29, TH30, TH31, TH32, TH33, TH34, TH35, TH36, TH37, TH38, TH39, TH40, TH41, TH42, TH43, TH44, TH45, TH46, TH47, TH48, TH49, TH50, TH51, TH52, TH53, TH54, TH55, TH56, TH57, TH58, TH59, TH60, TH61, TH62, TH63, TH64, TH65, TH66, TH67, TH68, TH69, TH70, TH71, TH72, TH73, TH74, TH75, TH76, TH77, TH78, TH79, TH80, TH81, TH82, TH83, TH84, TH85, TH86, TH87, TH88, TH89, TH90, TH91, TH92, TH93, TH94, TH95, TH96: NTC 10k B3434; R_0603_1608Metric; LCSC C13564

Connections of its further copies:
+3.3V: TH2.1, TH3.1, TH4.1, TH5.1, TH6.1, TH7.1, TH8.1, TH9.1, TH10.1, TH11.1, TH12.1, TH13.1, TH14.1, TH15.1, TH16.1, TH17.1, TH18.1, TH19.1, TH20.1, TH21.1, TH22.1, TH23.1, TH24.1, TH25.1, TH26.1, TH27.1, TH28.1, TH29.1, TH30.1, TH31.1, TH32.1, TH33.1, TH34.1, TH35.1, TH36.1, TH37.1, TH38.1, TH39.1, TH40.1, TH41.1, TH42.1, TH43.1, TH44.1, TH45.1, TH46.1, TH47.1, TH48.1, TH49.1, TH50.1, TH51.1, TH52.1, TH53.1, TH54.1, TH55.1, TH56.1, TH57.1, TH58.1, TH59.1, TH60.1, TH61.1, TH62.1, TH63.1, TH64.1, TH65.1, TH66.1, TH67.1, TH68.1, TH69.1, TH70.1, TH71.1, TH72.1, TH73.1, TH74.1, TH75.1, TH76.1, TH77.1, TH78.1, TH79.1, TH80.1, TH81.1, TH82.1, TH83.1, TH84.1, TH85.1, TH86.1, TH87.1, TH88.1, TH89.1, TH90.1, TH91.1, TH92.1, TH93.1, TH94.1, TH95.1, TH96.1; also elsewhere on the board
/LED_A1: LED37.1; also elsewhere on the board
/LED_A2: LED38.1; also elsewhere on the board
/LED_A3: LED39.1; also elsewhere on the board
/LED_A4: LED40.1; also elsewhere on the board
/LED_A5: LED25.1; also elsewhere on the board
/LED_A6: LED41.1; also elsewhere on the board
/LED_A7: LED26.1; also elsewhere on the board
/LED_A8: LED27.1; also elsewhere on the board
/LED_A9: LED13.1; also elsewhere on the board
/LED_A10: LED42.1; also elsewhere on the board
/LED_A11: LED28.1; also elsewhere on the board
/LED_A12: LED14.1; also elsewhere on the board
/LED_A13: LED15.1; also elsewhere on the board
/LED_A15: LED29.1; also elsewhere on the board
/LED_A16: LED2.1; also elsewhere on the board
/LED_A17: LED16.1; also elsewhere on the board
/LED_A18: LED3.1; also elsewhere on the board
/LED_A19: LED43.1; also elsewhere on the board
/LED_A20: LED17.1; also elsewhere on the board
/LED_A21: LED4.1; also elsewhere on the board
/LED_A22: LED30.1; also elsewhere on the board
/LED_A23: LED31.1; also elsewhere on the board
/LED_A24: LED18.1; also elsewhere on the board
/LED_A25: LED5.1; also elsewhere on the board
/LED_A26: LED44.1; also elsewhere on the board
/LED_A27: LED32.1; also elsewhere on the board
/LED_A28: LED6.1; also elsewhere on the board
/LED_A29: LED19.1; also elsewhere on the board
/LED_A30: LED45.1; also elsewhere on the board
/LED_A31: LED7.1; also elsewhere on the board
/LED_A32: LED20.1; also elsewhere on the board
/LED_A33: LED8.1; also elsewhere on the board
/LED_A34: LED33.1; also elsewhere on the board
/LED_A35: LED21.1; also elsewhere on the board
/LED_A36: LED9.1; also elsewhere on the board
/LED_A37: LED46.1; also elsewhere on the board
/LED_A38: LED34.1; also elsewhere on the board
/LED_A39: LED22.1; also elsewhere on the board
/LED_A40: LED10.1; also elsewhere on the board
/LED_A41: LED47.1; also elsewhere on the board
/LED_A42: LED35.1; also elsewhere on the board
/LED_A43: LED23.1; also elsewhere on the board
/LED_A44: LED11.1; also elsewhere on the board
/LED_A45: LED48.1; also elsewhere on the board
/LED_A46: LED36.1; also elsewhere on the board
/LED_A47: LED24.1; also elsewhere on the board
/LED_A48: LED12.1; also elsewhere on the board
/LED_A49: LED65.1; also elsewhere on the board
/LED_A50: LED86.1; also elsewhere on the board
/LED_A51: LED75.1; also elsewhere on the board
/LED_A52: LED85.1; also elsewhere on the board
/LED_A53: LED54.1; also elsewhere on the board
/LED_A54: LED64.1; also elsewhere on the board
/LED_A55: LED74.1; also elsewhere on the board
/LED_A56: LED53.1; also elsewhere on the board
/LED_A57: LED73.1; also elsewhere on the board
/LED_A58: LED63.1; also elsewhere on the board
/LED_A59: LED62.1; also elsewhere on the board
/LED_A60: LED52.1; also elsewhere on the board
/LED_A61: LED61.1; also elsewhere on the board
/LED_A62: LED51.1; also elsewhere on the board
/LED_A63: LED50.1; also elsewhere on the board
/LED_A64: LED49.1; also elsewhere on the board
/LED_A65: LED87.1; also elsewhere on the board
/LED_A66: LED76.1; also elsewhere on the board
/LED_A67: LED55.1; also elsewhere on the board
/LED_A68: LED88.1; also elsewhere on the board
/LED_A69: LED66.1; also elsewhere on the board
/LED_A70: LED77.1; also elsewhere on the board
/LED_A71: LED56.1; also elsewhere on the board
/LED_A72: LED78.1; also elsewhere on the board
/LED_A73: LED89.1; also elsewhere on the board
/LED_A74: LED67.1; also elsewhere on the board
/LED_A75: LED90.1; also elsewhere on the board
/LED_A76: LED79.1; also elsewhere on the board
/LED_A77: LED68.1; also elsewhere on the board
/LED_A78: LED57.1; also elsewhere on the board
/LED_A79: LED91.1; also elsewhere on the board
/LED_A80: LED80.1; also elsewhere on the board
/LED_A81: LED92.1; also elsewhere on the board
/LED_A82: LED69.1; also elsewhere on the board
/LED_A83: LED81.1; also elsewhere on the board
/LED_A84: LED93.1; also elsewhere on the board
/LED_A85: LED58.1; also elsewhere on the board
/LED_A86: LED70.1; also elsewhere on the board
/LED_A87: LED82.1; also elsewhere on the board
/LED_A88: LED94.1; also elsewhere on the board
/LED_A89: LED59.1; also elsewhere on the board
/LED_A90: LED71.1; also elsewhere on the board
/LED_A91: LED83.1; also elsewhere on the board
/LED_A92: LED95.1; also elsewhere on the board
/LED_A93: LED60.1; also elsewhere on the board
/LED_A94: LED72.1; also elsewhere on the board
/LED_A95: LED84.1; also elsewhere on the board
/LED_A96: LED96.1; also elsewhere on the board
/LED_K1: LED37.2, LED37.3; also elsewhere on the board
/LED_K2: LED38.2, LED38.3; also elsewhere on the board
/LED_K3: LED39.2, LED39.3; also elsewhere on the board
/LED_K4: LED40.2, LED40.3; also elsewhere on the board
/LED_K5: LED25.2, LED25.3; also elsewhere on the board
/LED_K6: LED41.2, LED41.3; also elsewhere on the board
/LED_K7: LED26.2, LED26.3; also elsewhere on the board
/LED_K8: LED27.2, LED27.3; also elsewhere on the board
/LED_K9: LED13.2, LED13.3; also elsewhere on the board
/LED_K10: LED42.2, LED42.3; also elsewhere on the board
/LED_K11: LED28.2, LED28.3; also elsewhere on the board
/LED_K12: LED14.2, LED14.3; also elsewhere on the board
/LED_K13: LED15.2, LED15.3; also elsewhere on the board
/LED_K15: LED29.2, LED29.3; also elsewhere on the board
/LED_K16: LED2.2, LED2.3; also elsewhere on the board
/LED_K17: LED16.2, LED16.3; also elsewhere on the board
/LED_K18: LED3.2, LED3.3; also elsewhere on the board
/LED_K19: LED43.2, LED43.3; also elsewhere on the board
/LED_K20: LED17.2, LED17.3; also elsewhere on the board
/LED_K21: LED4.2, LED4.3; also elsewhere on the board
/LED_K22: LED30.2, LED30.3; also elsewhere on the board
/LED_K23: LED31.2, LED31.3; also elsewhere on the board
/LED_K24: LED18.2, LED18.3; also elsewhere on the board
/LED_K25: LED5.2, LED5.3; also elsewhere on the board
/LED_K26: LED44.2, LED44.3; also elsewhere on the board
/LED_K27: LED32.2, LED32.3; also elsewhere on the board
/LED_K28: LED6.2, LED6.3; also elsewhere on the board
/LED_K29: LED19.2, LED19.3; also elsewhere on the board
/LED_K30: LED45.2, LED45.3; also elsewhere on the board
/LED_K31: LED7.2, LED7.3; also elsewhere on the board
/LED_K32: LED20.2, LED20.3; also elsewhere on the board
/LED_K33: LED8.2, LED8.3; also elsewhere on the board
/LED_K34: LED33.2, LED33.3; also elsewhere on the board
/LED_K35: LED21.2, LED21.3; also elsewhere on the board
/LED_K36: LED9.2, LED9.3; also elsewhere on the board
/LED_K37: LED46.2, LED46.3; also elsewhere on the board
/LED_K38: LED34.2, LED34.3; also elsewhere on the board
/LED_K39: LED22.2, LED22.3; also elsewhere on the board
/LED_K40: LED10.2, LED10.3; also elsewhere on the board
/LED_K41: LED47.2, LED47.3; also elsewhere on the board
/LED_K42: LED35.2, LED35.3; also elsewhere on the board
/LED_K43: LED23.2, LED23.3; also elsewhere on the board
/LED_K44: LED11.2, LED11.3; also elsewhere on the board
/LED_K45: LED48.2, LED48.3; also elsewhere on the board
/LED_K46: LED36.2, LED36.3; also elsewhere on the board
/LED_K47: LED24.2, LED24.3; also elsewhere on the board
/LED_K48: LED12.2, LED12.3; also elsewhere on the board
/LED_K49: LED65.2, LED65.3; also elsewhere on the board
/LED_K50: LED86.2, LED86.3; also elsewhere on the board
/LED_K51: LED75.2, LED75.3; also elsewhere on the board
/LED_K52: LED85.2, LED85.3; also elsewhere on the board
/LED_K53: LED54.2, LED54.3; also elsewhere on the board
/LED_K54: LED64.2, LED64.3; also elsewhere on the board
/LED_K55: LED74.2, LED74.3; also elsewhere on the board
/LED_K56: LED53.2, LED53.3; also elsewhere on the board
/LED_K57: LED73.2, LED73.3; also elsewhere on the board
/LED_K58: LED63.2, LED63.3; also elsewhere on the board
/LED_K59: LED62.2, LED62.3; also elsewhere on the board
/LED_K60: LED52.2, LED52.3; also elsewhere on the board
/LED_K61: LED61.2, LED61.3; also elsewhere on the board
/LED_K62: LED51.2, LED51.3; also elsewhere on the board
/LED_K63: LED50.2, LED50.3; also elsewhere on the board
/LED_K64: LED49.2, LED49.3; also elsewhere on the board
/LED_K65: LED87.2, LED87.3; also elsewhere on the board
/LED_K66: LED76.2, LED76.3; also elsewhere on the board
/LED_K67: LED55.2, LED55.3; also elsewhere on the board
/LED_K68: LED88.2, LED88.3; also elsewhere on the board
/LED_K69: LED66.2, LED66.3; also elsewhere on the board
/LED_K70: LED77.2, LED77.3; also elsewhere on the board
/LED_K71: LED56.2, LED56.3; also elsewhere on the board
/LED_K72: LED78.2, LED78.3; also elsewhere on the board
/LED_K73: LED89.2, LED89.3; also elsewhere on the board
/LED_K74: LED67.2, LED67.3; also elsewhere on the board
/LED_K75: LED90.2, LED90.3; also elsewhere on the board
/LED_K76: LED79.2, LED79.3; also elsewhere on the board
/LED_K77: LED68.2, LED68.3; also elsewhere on the board
/LED_K78: LED57.2, LED57.3; also elsewhere on the board
/LED_K79: LED91.2, LED91.3; also elsewhere on the board
/LED_K80: LED80.2, LED80.3; also elsewhere on the board
/LED_K81: LED92.2, LED92.3; also elsewhere on the board
/LED_K82: LED69.2, LED69.3; also elsewhere on the board
/LED_K83: LED81.2, LED81.3; also elsewhere on the board
/LED_K84: LED93.2, LED93.3; also elsewhere on the board
/LED_K85: LED58.2, LED58.3; also elsewhere on the board
/LED_K86: LED70.2, LED70.3; also elsewhere on the board
/LED_K87: LED82.2, LED82.3; also elsewhere on the board
/LED_K88: LED94.2, LED94.3; also elsewhere on the board
/LED_K89: LED59.2, LED59.3; also elsewhere on the board
/LED_K90: LED71.2, LED71.3; also elsewhere on the board
/LED_K91: LED83.2, LED83.3; also elsewhere on the board
/LED_K92: LED95.2, LED95.3; also elsewhere on the board
/LED_K93: LED60.2, LED60.3; also elsewhere on the board
/LED_K94: LED72.2, LED72.3; also elsewhere on the board
/LED_K95: LED84.2, LED84.3; also elsewhere on the board
/LED_K96: LED96.2, LED96.3; also elsewhere on the board
/NTC2: R2.1, TH2.2; also elsewhere on the board
/NTC3: R3.1, TH3.2; also elsewhere on the board
/NTC4: R4.1, TH4.2; also elsewhere on the board
/NTC5: R5.1, TH5.2; also elsewhere on the board
/NTC6: R6.1, TH6.2; also elsewhere on the board
/NTC7: R7.1, TH7.2; also elsewhere on the board
/NTC8: R8.1, TH8.2; also elsewhere on the board
/NTC9: R9.1, TH9.2; also elsewhere on the board
/NTC10: R10.1, TH10.2; also elsewhere on the board
/NTC11: R11.1, TH11.2; also elsewhere on the board
/NTC12: R12.1, TH12.2; also elsewhere on the board
/NTC13: R13.1, TH13.2; also elsewhere on the board
/NTC14: R14.1, TH14.2; also elsewhere on the board
/NTC15: R15.1, TH15.2; also elsewhere on the board
/NTC16: R16.1, TH16.2; also elsewhere on the board
/NTC17: R17.1, TH17.2; also elsewhere on the board
/NTC18: R18.1, TH18.2; also elsewhere on the board
/NTC19: R19.1, TH19.2; also elsewhere on the board
/NTC20: R20.1, TH20.2; also elsewhere on the board
/NTC21: R21.1, TH21.2; also elsewhere on the board
/NTC22: R22.1, TH22.2; also elsewhere on the board
/NTC23: R23.1, TH23.2; also elsewhere on the board
/NTC24: R24.1, TH24.2; also elsewhere on the board
/NTC25: R25.1, TH25.2; also elsewhere on the board
/NTC26: R26.1, TH26.2; also elsewhere on the board
/NTC27: R27.1, TH27.2; also elsewhere on the board
/NTC28: R28.1, TH28.2; also elsewhere on the board
/NTC29: R29.1, TH29.2; also elsewhere on the board
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

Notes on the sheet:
One well: 660nm LED (pad3 thermal tied to cathode) + 10k NTC / 10k 1% divider from 3V3.
Instantiated 96x from the root sheet (CH01..CH96).

Board: 4 copper layers, 315 parts (0 on the bottom side), 300 nets, no tracks yet.

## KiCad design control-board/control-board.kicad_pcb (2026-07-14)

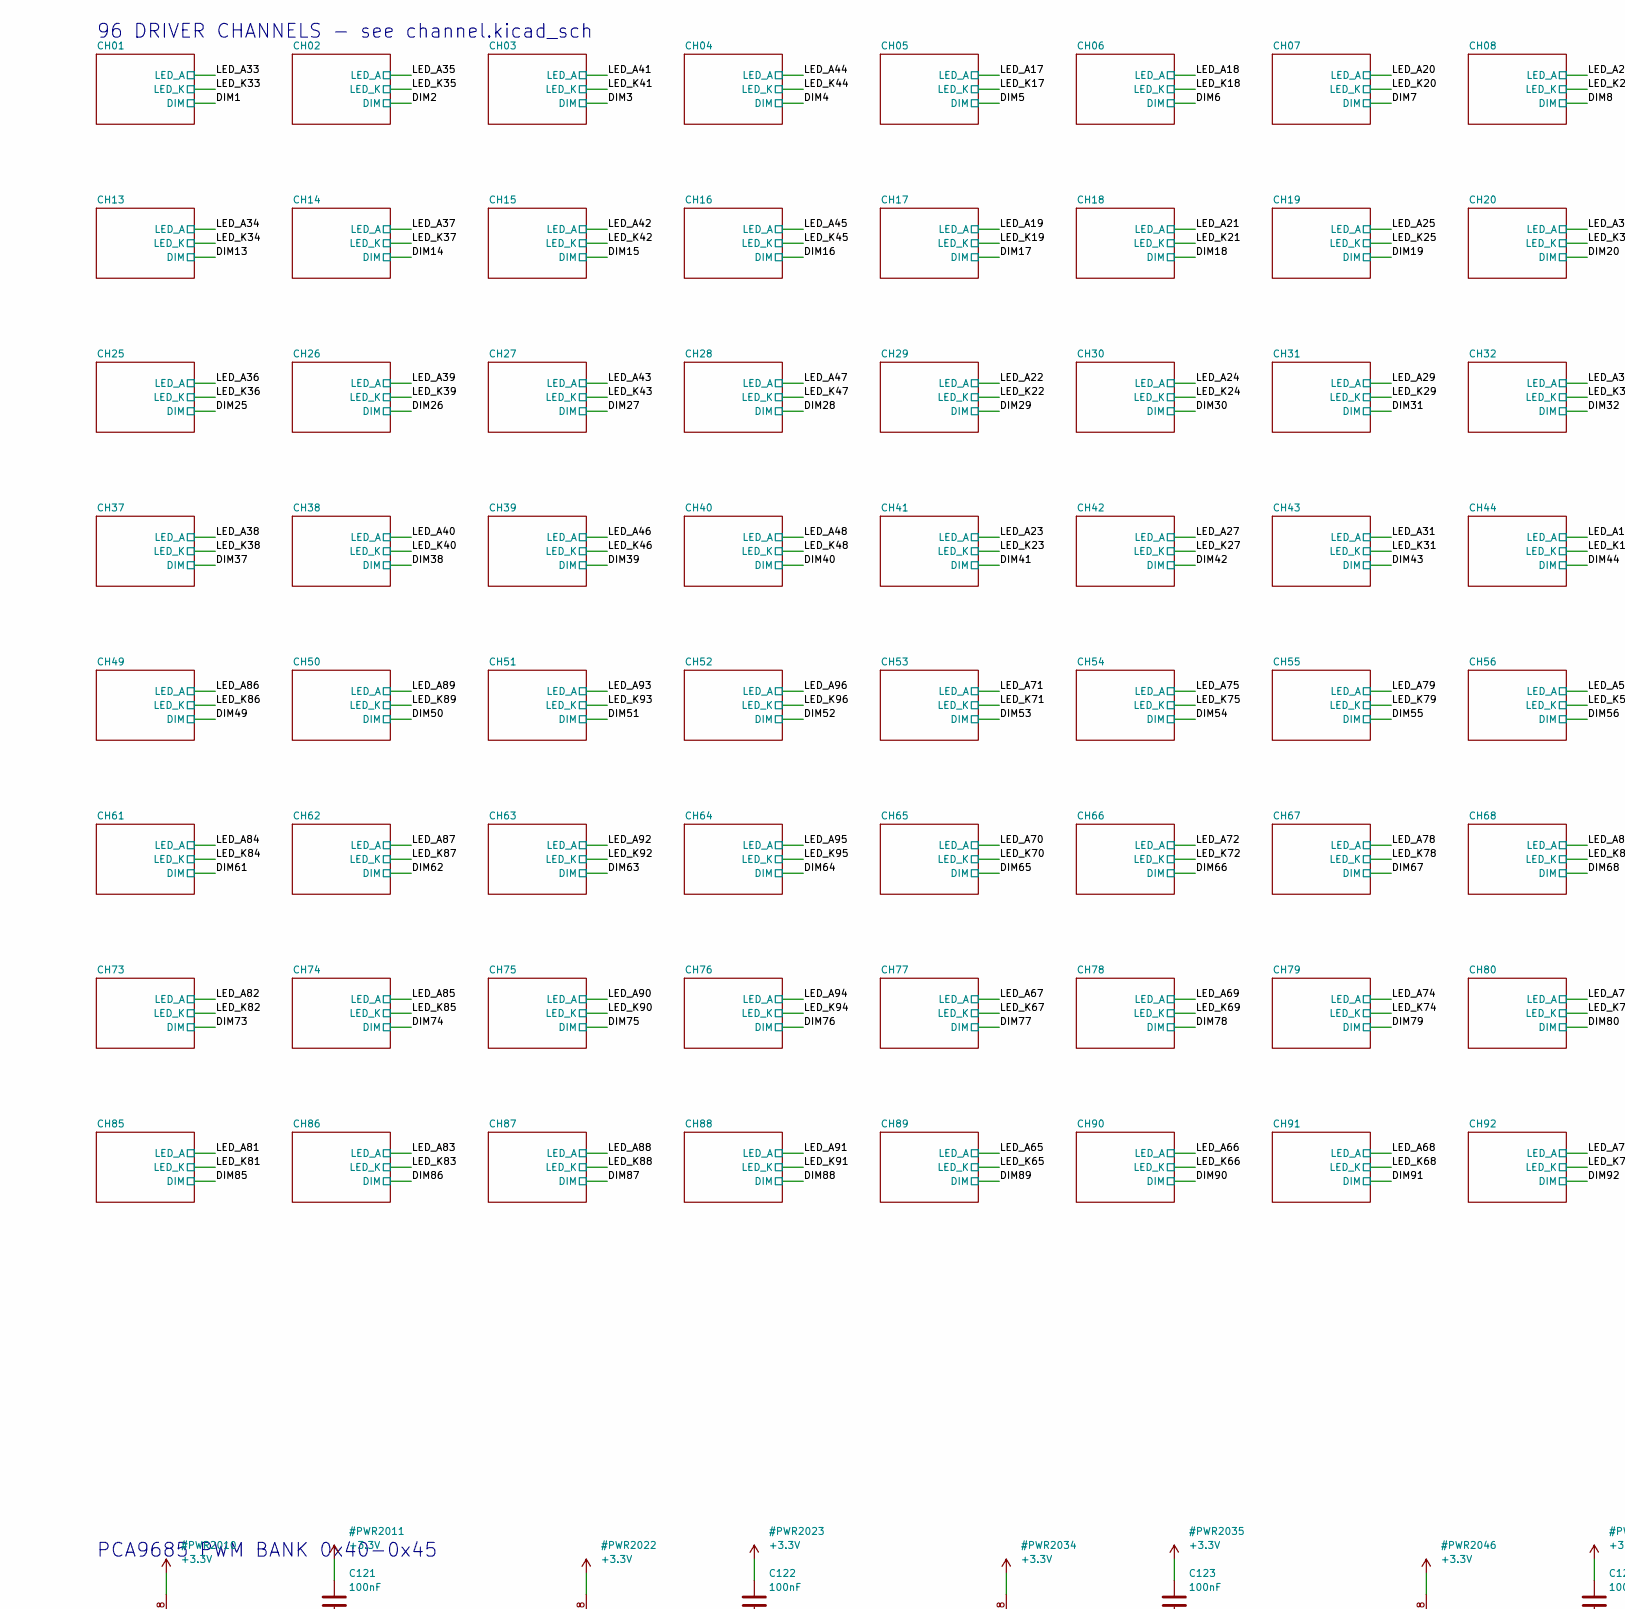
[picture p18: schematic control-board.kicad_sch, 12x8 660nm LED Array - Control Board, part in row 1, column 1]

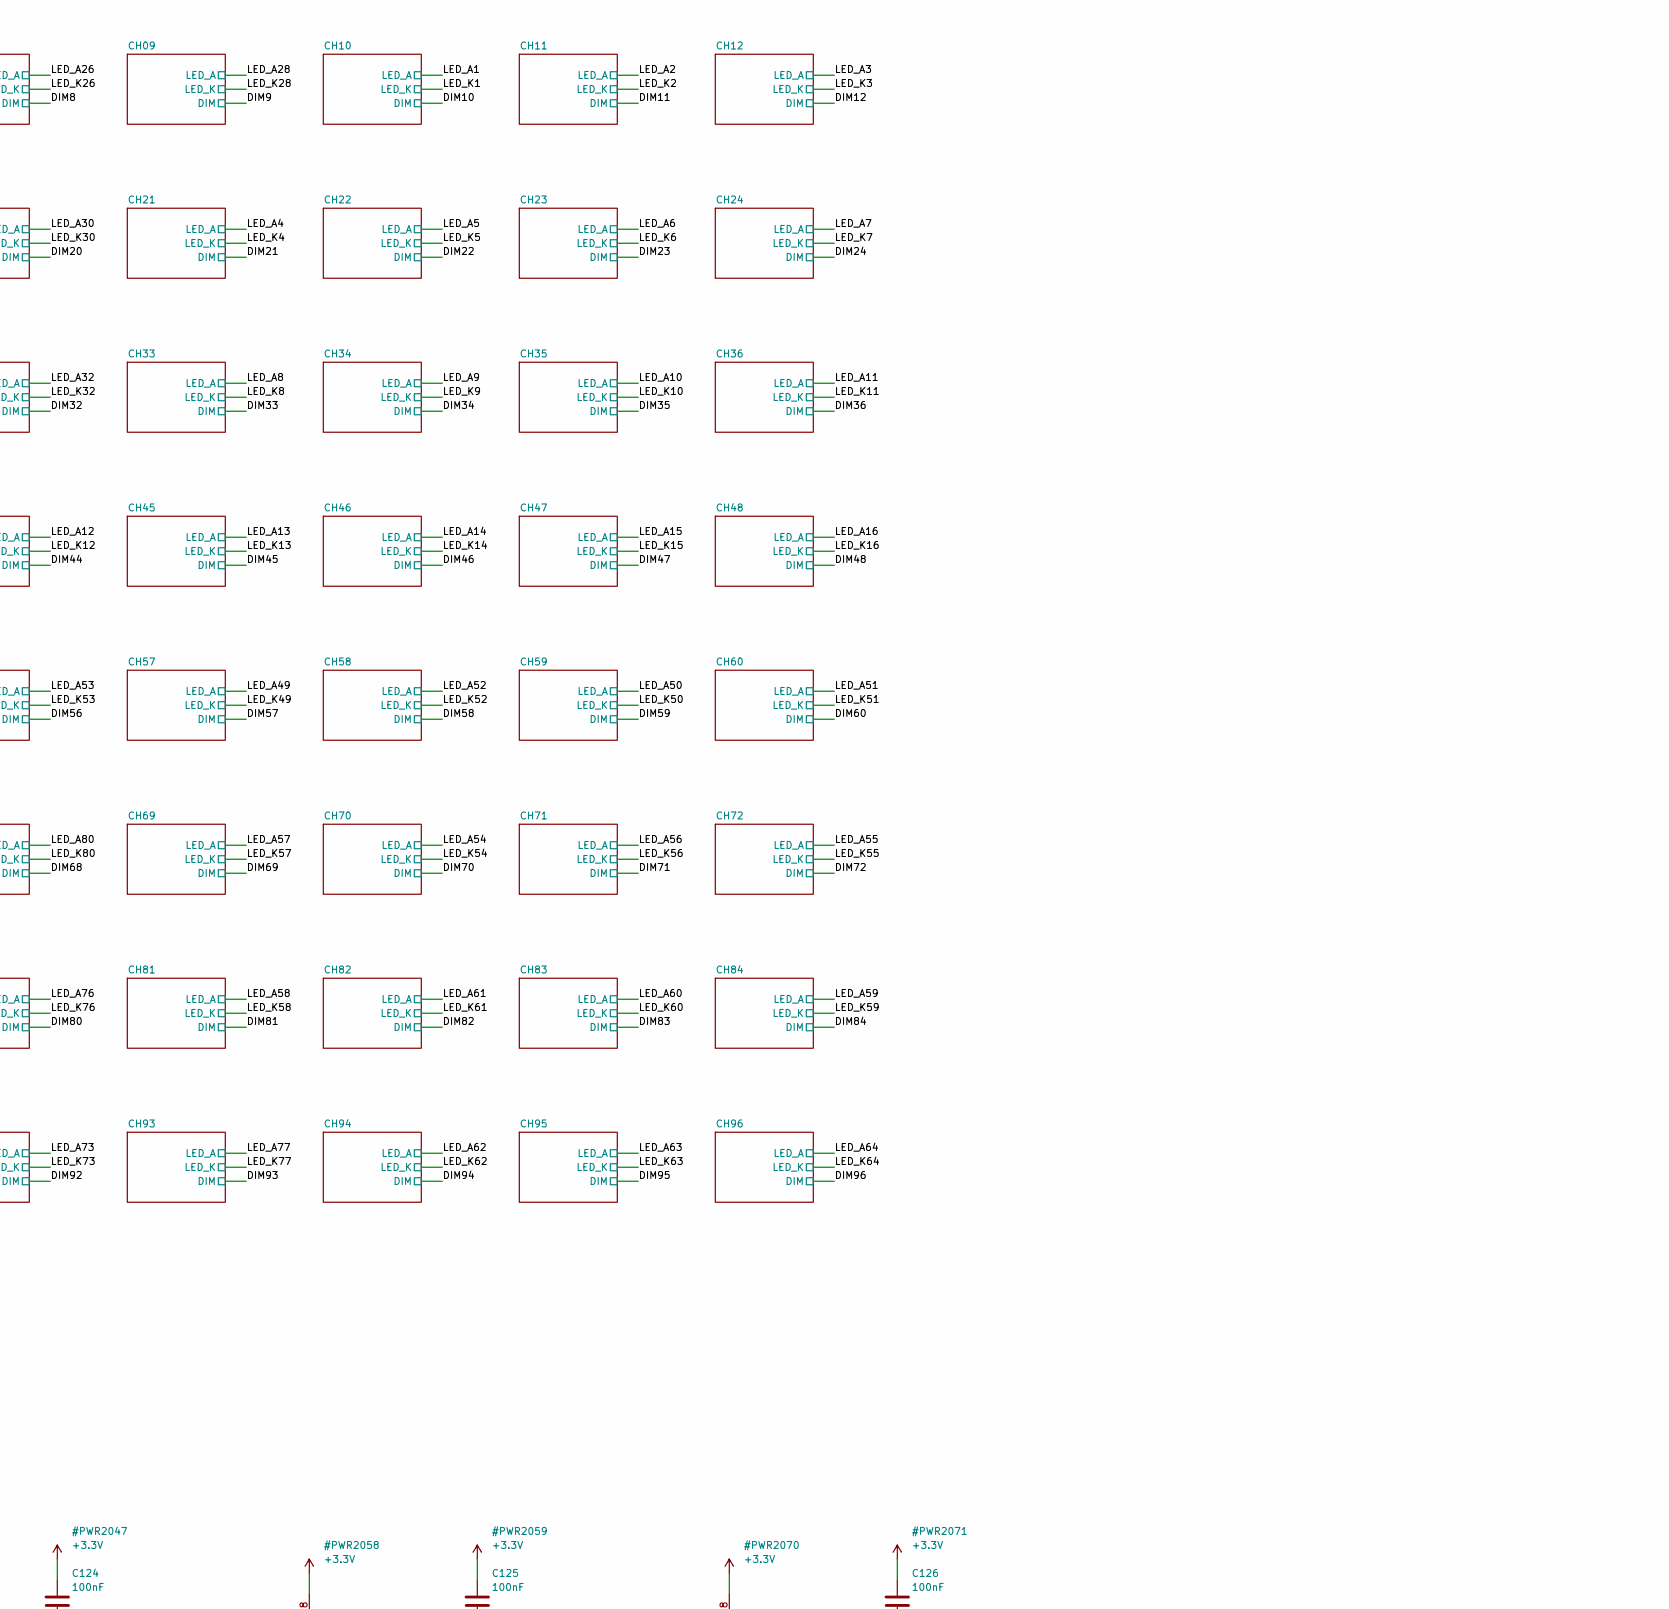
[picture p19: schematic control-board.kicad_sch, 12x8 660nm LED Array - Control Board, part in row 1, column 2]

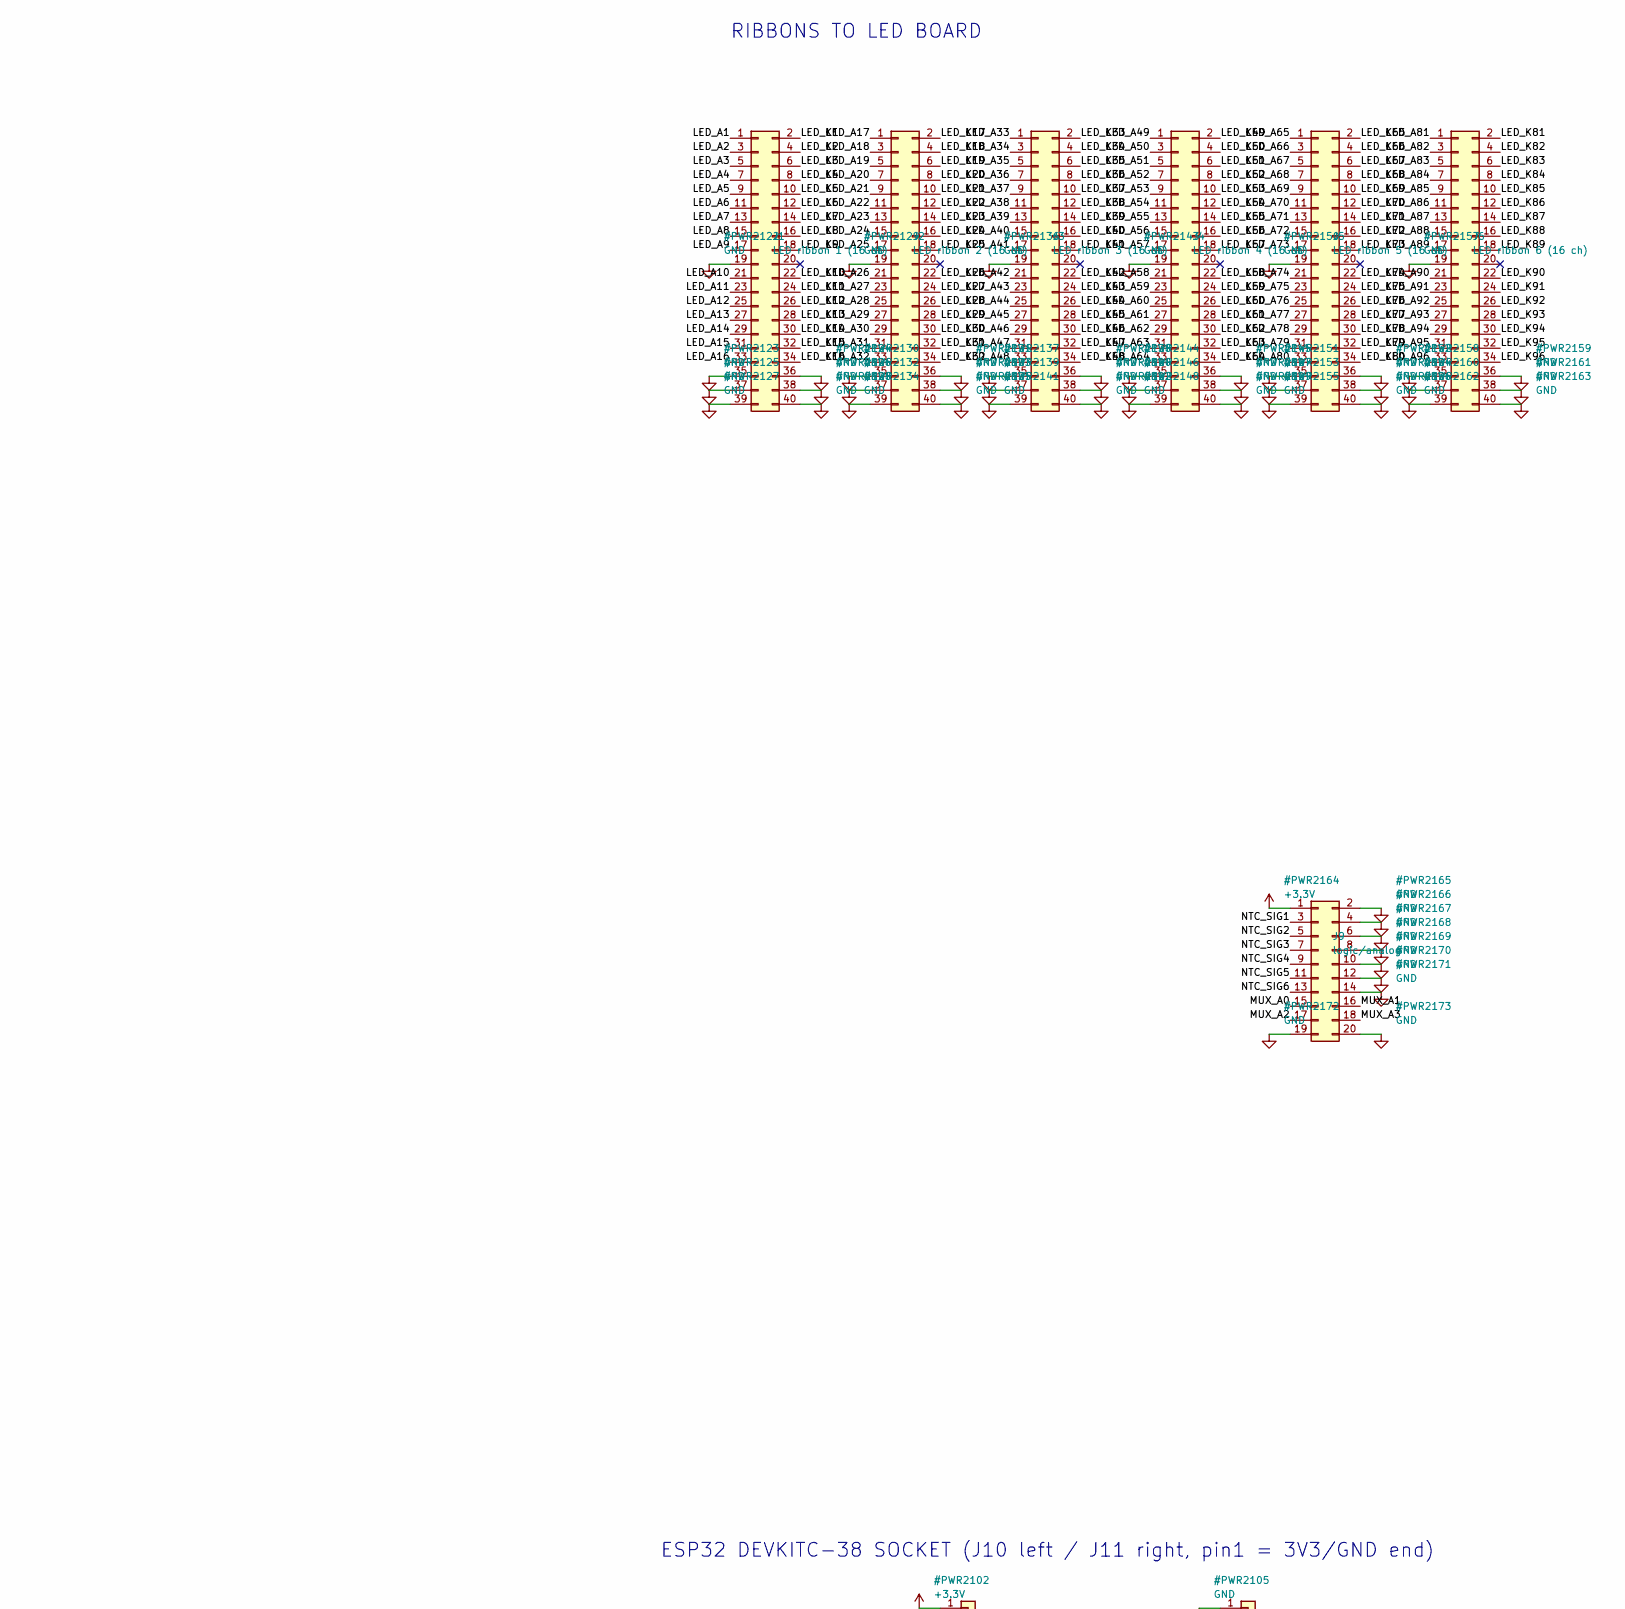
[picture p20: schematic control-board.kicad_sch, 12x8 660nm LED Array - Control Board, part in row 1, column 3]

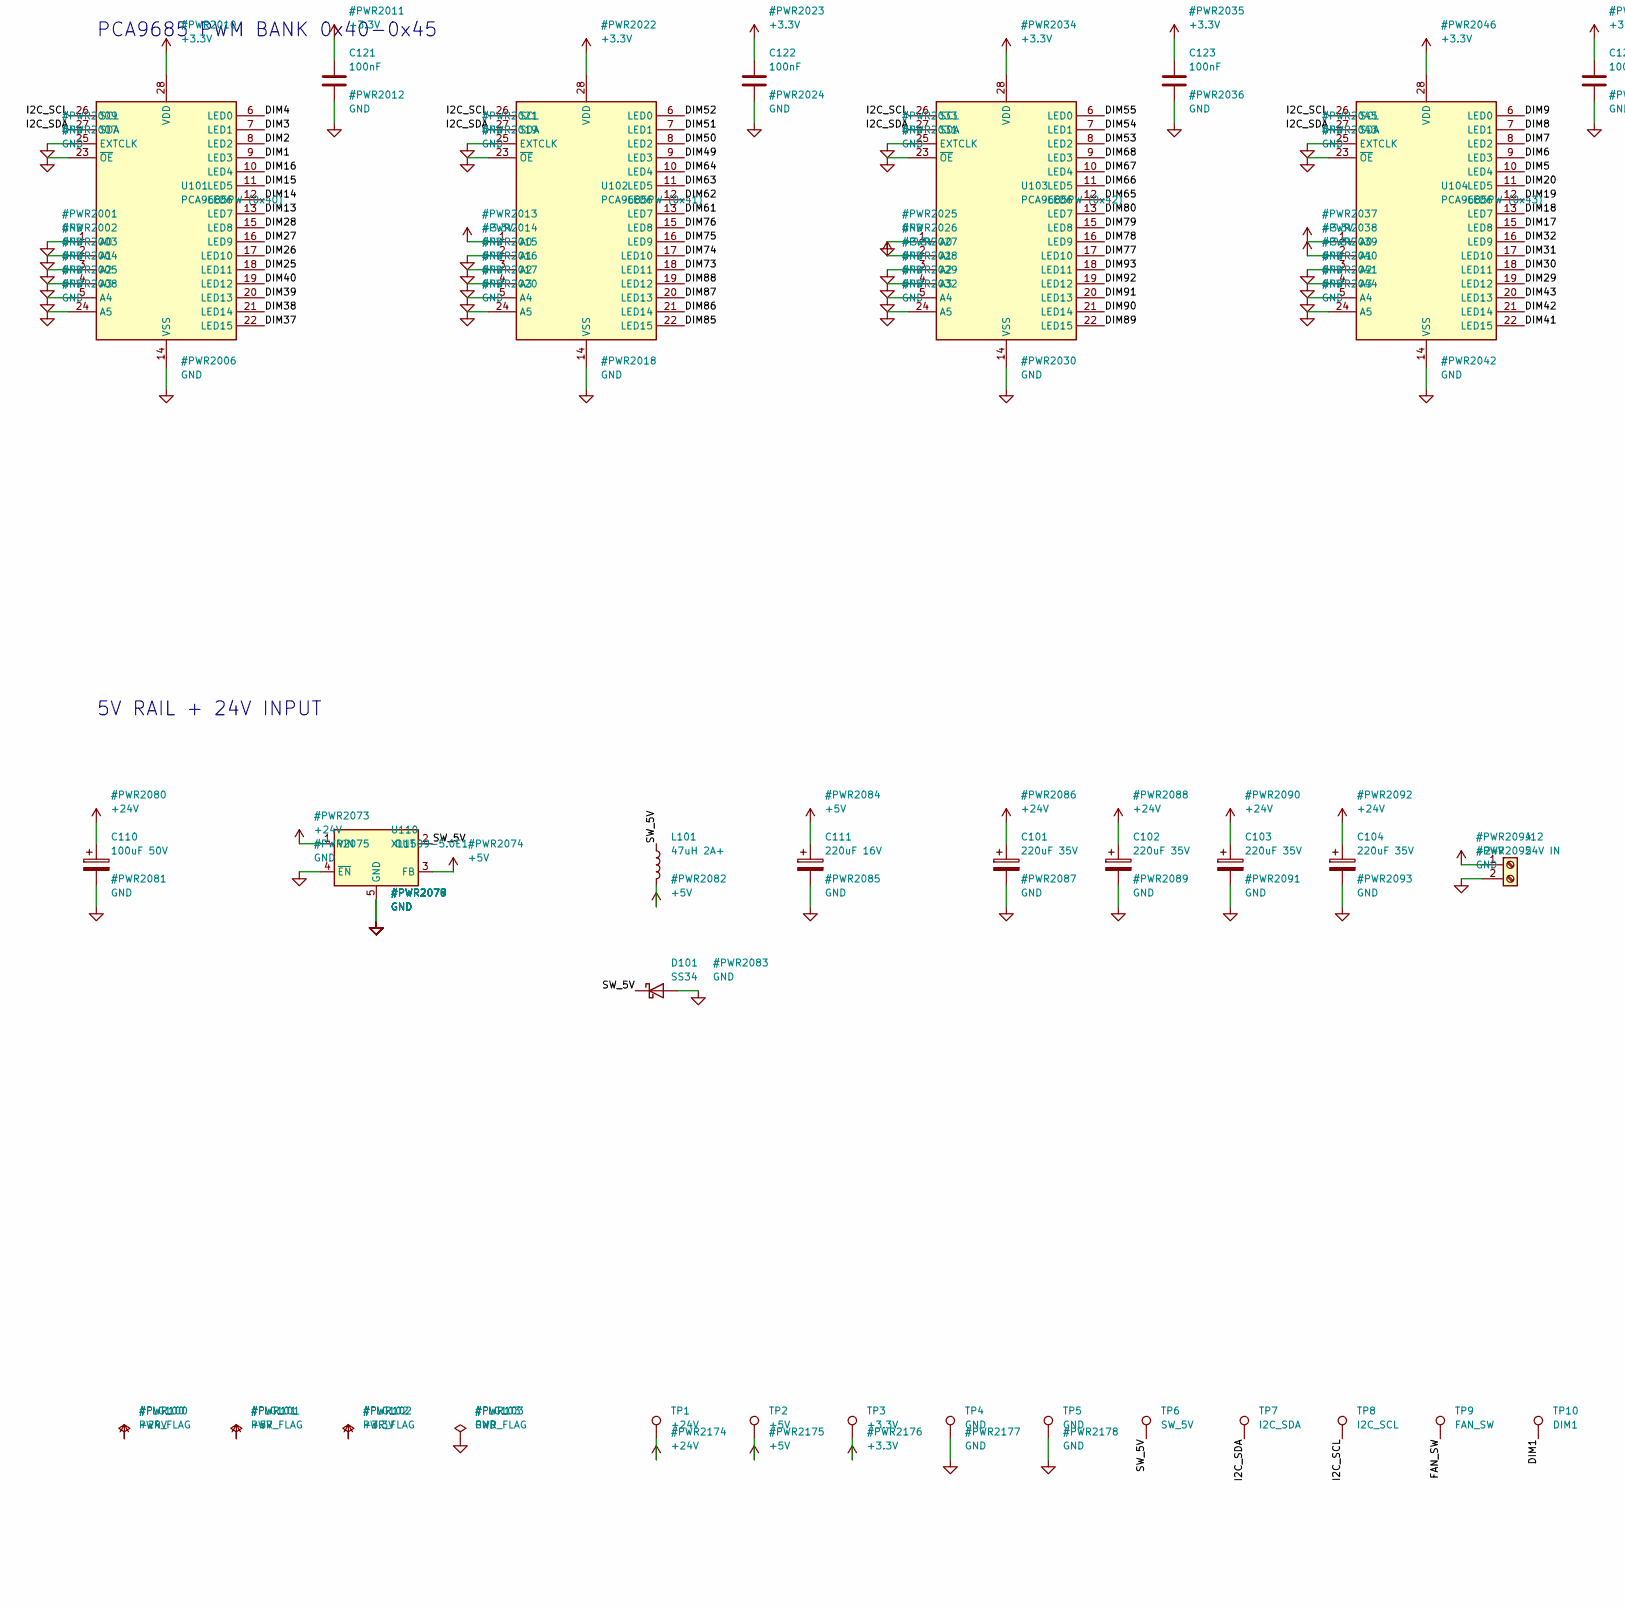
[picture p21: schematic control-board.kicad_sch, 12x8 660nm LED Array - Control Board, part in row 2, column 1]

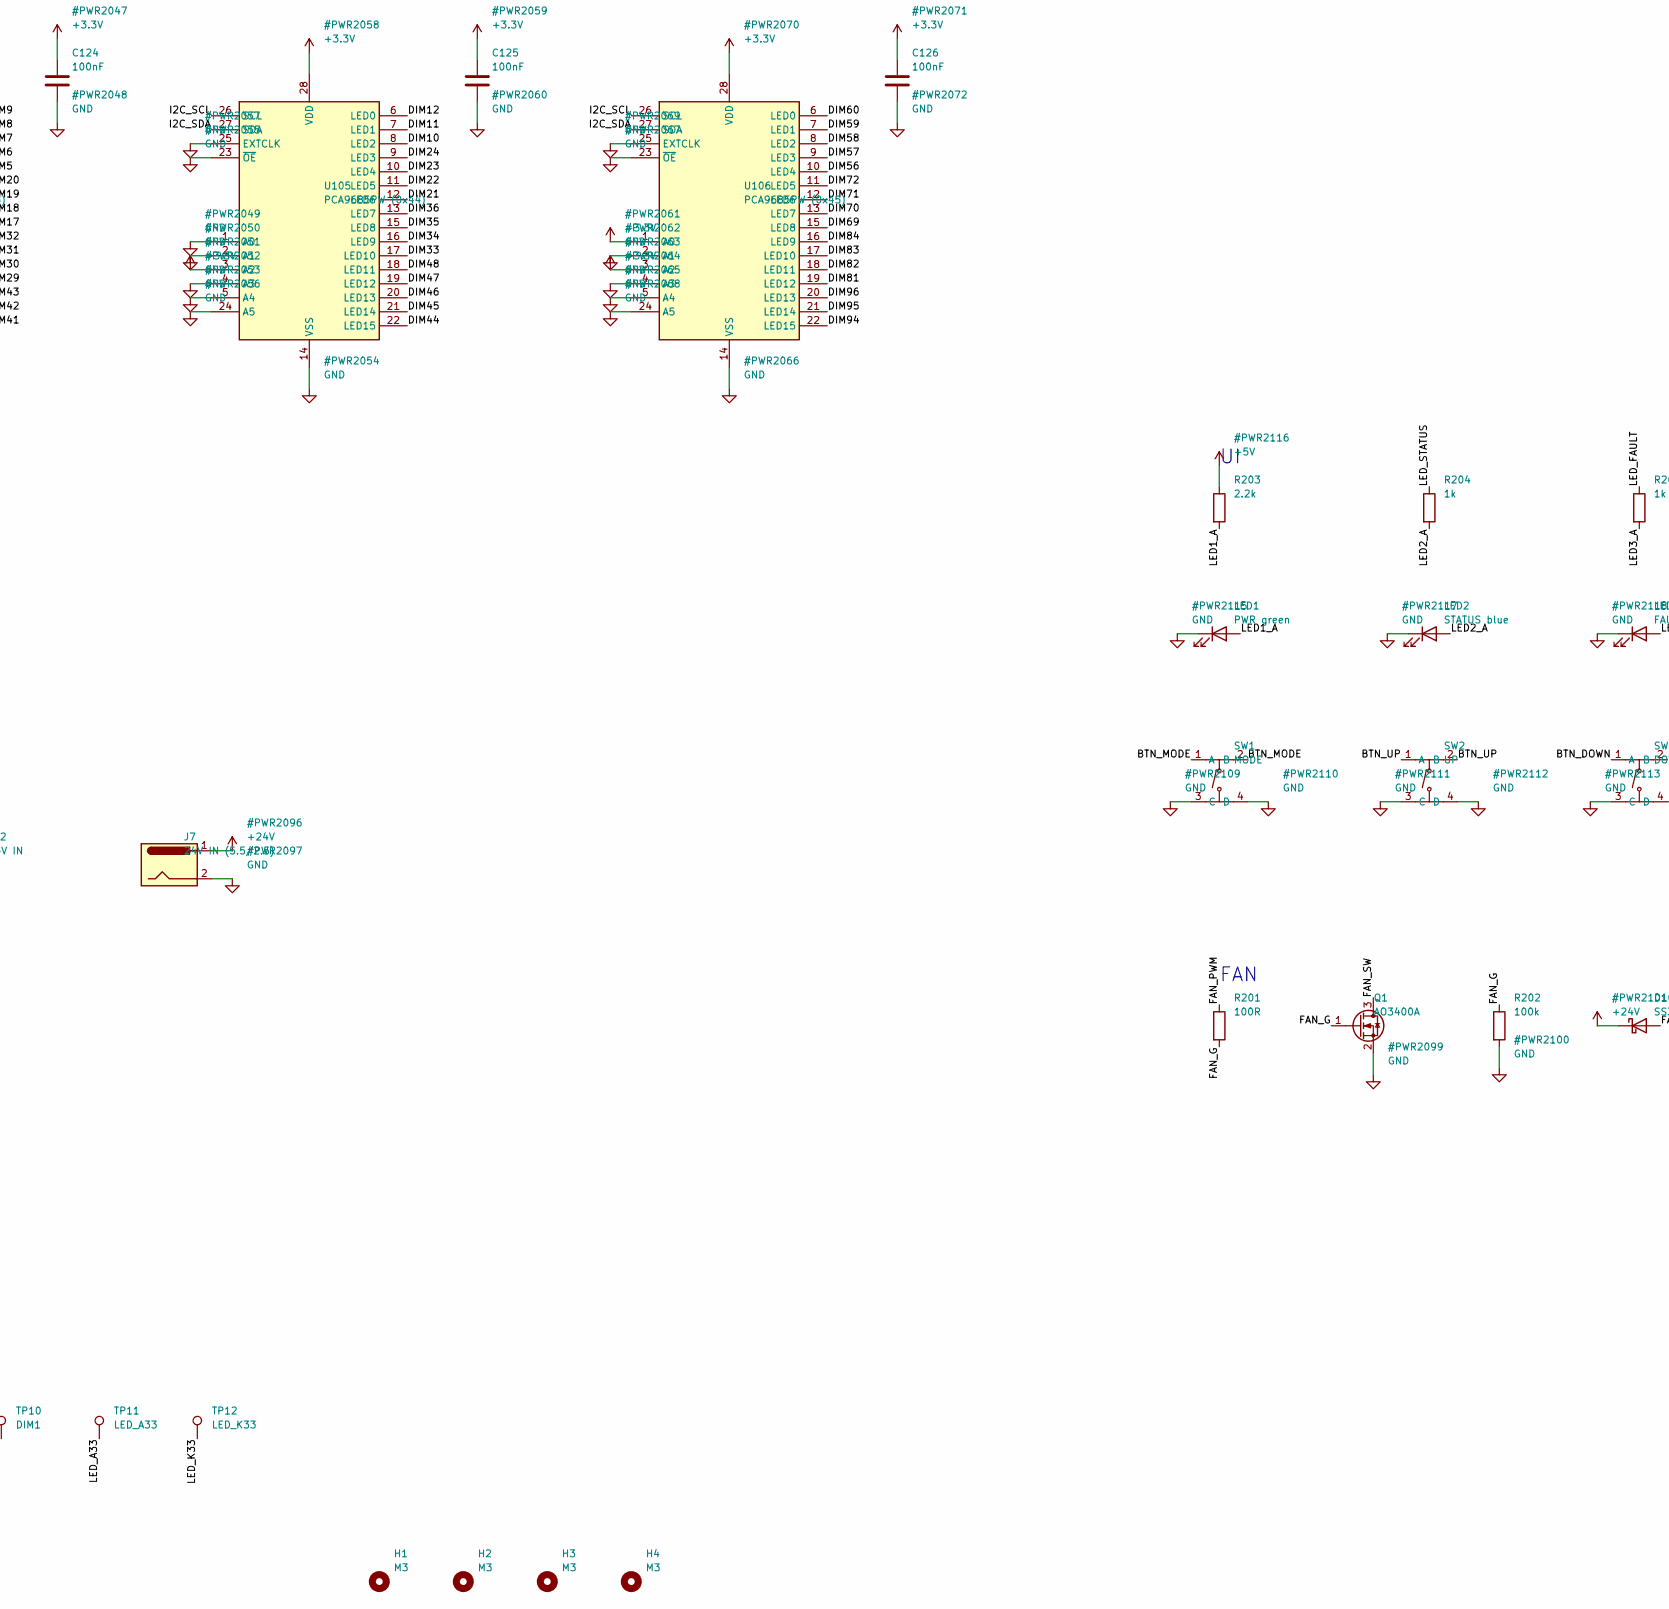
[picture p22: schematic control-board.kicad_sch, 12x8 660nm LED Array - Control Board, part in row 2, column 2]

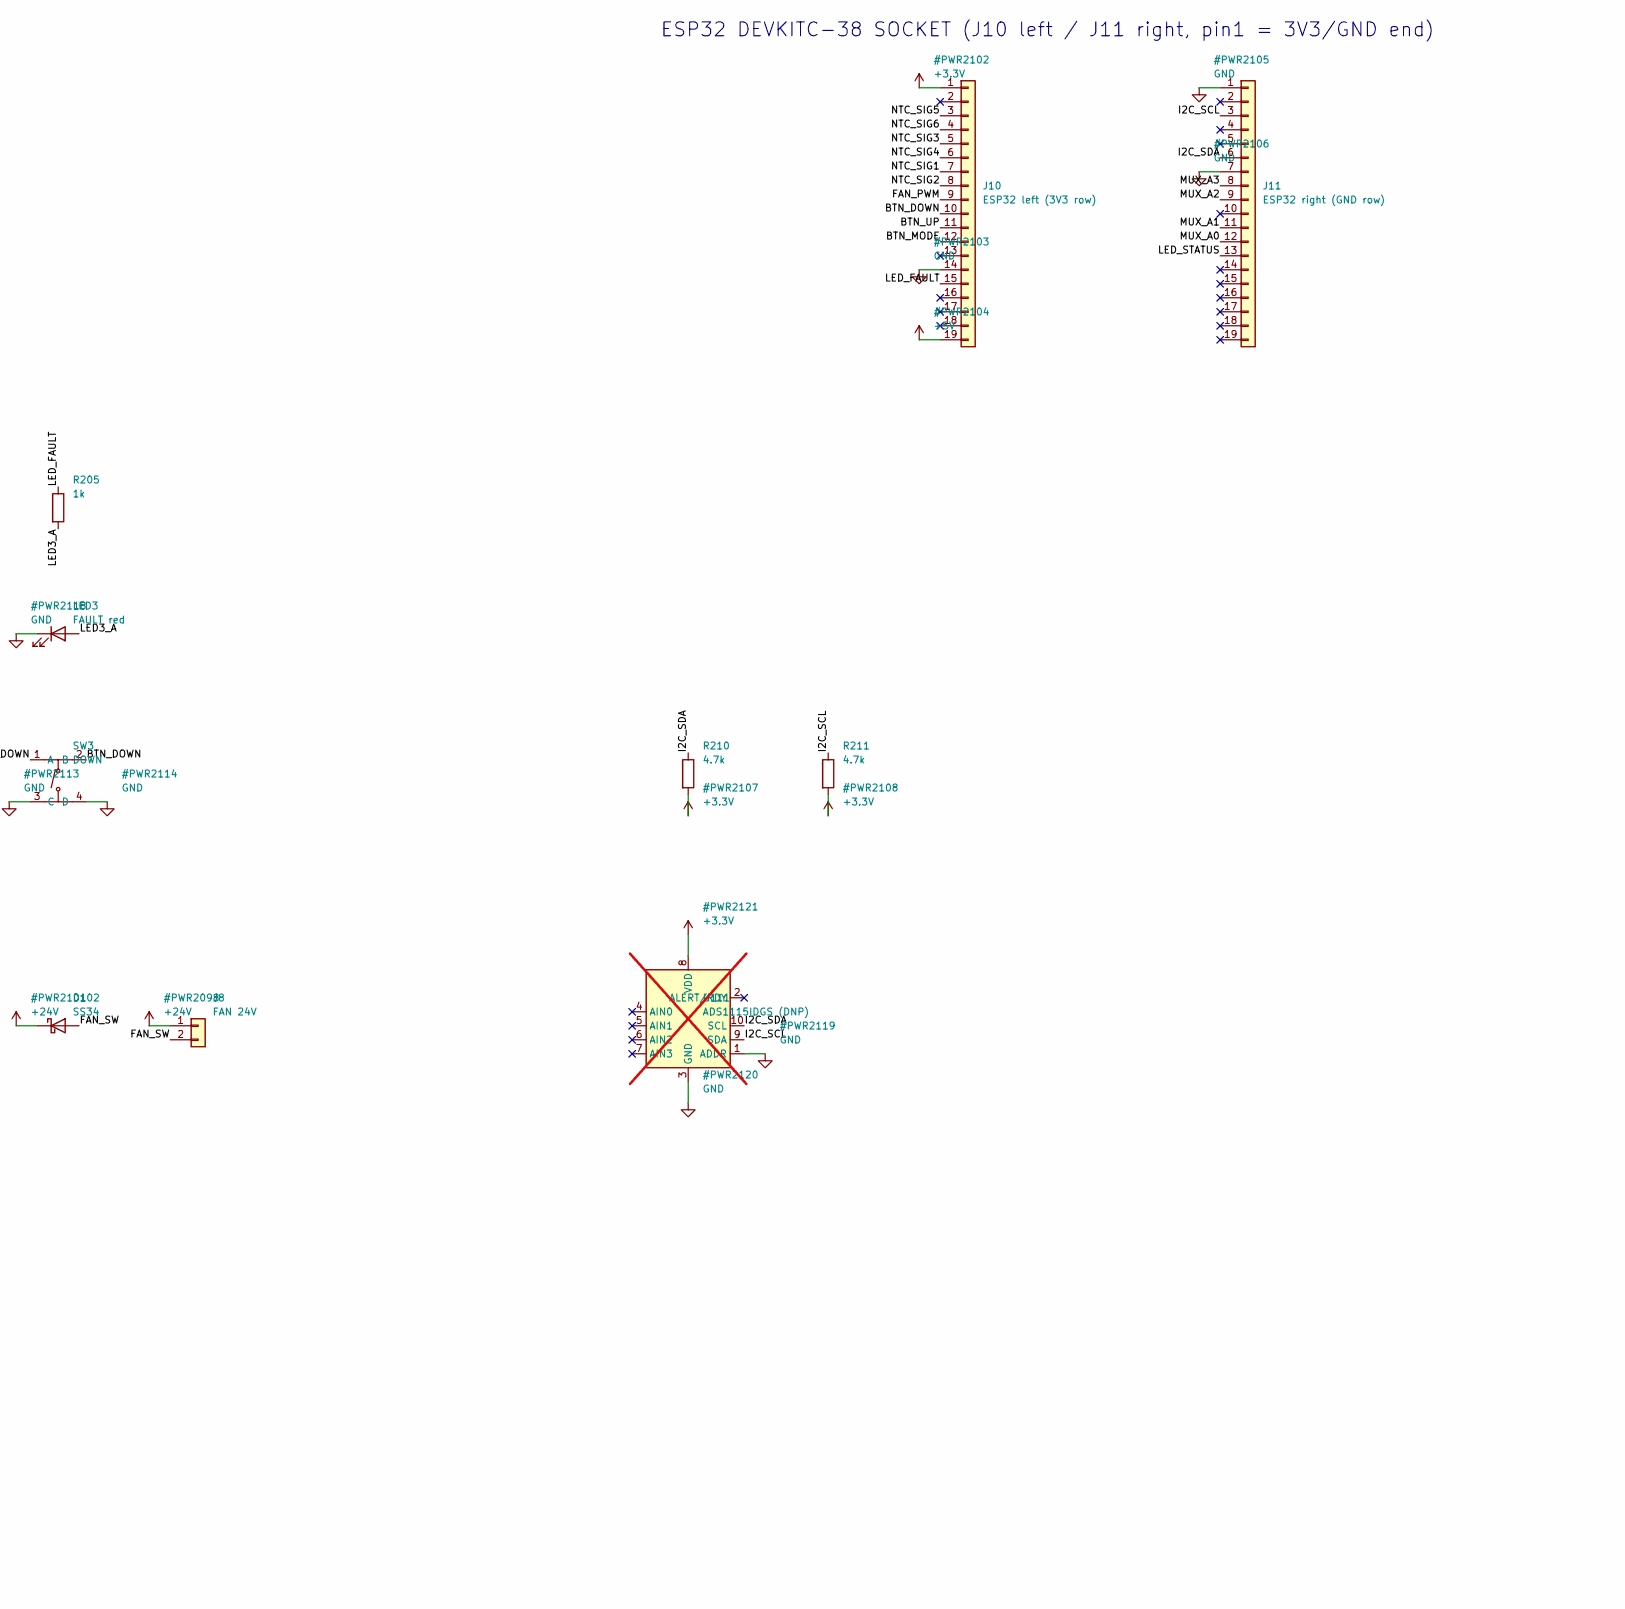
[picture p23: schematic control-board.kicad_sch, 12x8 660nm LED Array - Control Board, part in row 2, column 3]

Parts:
C101, C102, C103, C104: 220uF 35V; CP_Elec_8x10; LCSC C134820
C110: 100uF 50V; CP_Elec_8x10; LCSC C134514
C111: 220uF 16V; CP_Elec_6.3x7.7; LCSC C286136
C121, C122, C123, C124, C125, C126: 100nF; C_0603_1608Metric; LCSC C14663
D101, D102: SS34; D_SMA; LCSC C8678
H1, H2, H3, H4: M3; MountingHole_3.2mm_M3
J1: LED ribbon 1 (16 ch); IDC-Header_2x20_P2.54mm_Vertical; LCSC C9043
J2: LED ribbon 2 (16 ch); IDC-Header_2x20_P2.54mm_Vertical; LCSC C9043
J3: LED ribbon 3 (16 ch); IDC-Header_2x20_P2.54mm_Vertical; LCSC C9043
J4: LED ribbon 4 (16 ch); IDC-Header_2x20_P2.54mm_Vertical; LCSC C9043
J5: LED ribbon 5 (16 ch); IDC-Header_2x20_P2.54mm_Vertical; LCSC C9043
J6: LED ribbon 6 (16 ch); IDC-Header_2x20_P2.54mm_Vertical; LCSC C9043
J7: 24V IN (5.5/2.5); BarrelJack_Horizontal; LCSC C381115
J8: FAN 24V; PinHeader_1x02_P2.54mm_Vertical; LCSC C2337
J9: logic/analog; IDC-Header_2x10_P2.54mm_Horizontal; LCSC C9144
J10: ESP32 left (3V3 row); PinSocket_1x19_P2.54mm_Vertical; LCSC C319202
J11: ESP32 right (GND row); PinSocket_1x19_P2.54mm_Vertical; LCSC C319202
J12: 24V IN; TerminalBlock_KF301-5.0-2P_1x02_P5.00mm; LCSC C474881
L101: 47uH 2A+; L_Sunlord_SWPA6045S; LCSC C36414
LED1: PWR green; LED_0805_2012Metric; LCSC C2297
LED2: STATUS blue; LED_0805_2012Metric; LCSC C2293
LED3: FAULT red; LED_0805_2012Metric; LCSC C84256
Q1: AO3400A; SOT-23; LCSC C20917
R201: 100R; R_0603_1608Metric; LCSC C22775
R202: 100k; R_0603_1608Metric; LCSC C25803
R203: 2.2k; R_0603_1608Metric; LCSC C4190
R204, R205: 1k; R_0603_1608Metric; LCSC C21190
R210, R211: 4.7k; R_0603_1608Metric; LCSC C23162
SW1: MODE; SW-SMD_4P-L5.1-W5.1-P3.70-LS6.5-TL_H1.5; LCSC C318884
SW2: UP; SW-SMD_4P-L5.1-W5.1-P3.70-LS6.5-TL_H1.5; LCSC C318884
SW3: DOWN; SW-SMD_4P-L5.1-W5.1-P3.70-LS6.5-TL_H1.5; LCSC C318884
TP1: +24V; TestPoint_Pad_1.5x1.5mm
TP2: +5V; TestPoint_Pad_1.5x1.5mm
TP3: +3.3V; TestPoint_Pad_1.5x1.5mm
TP4, TP5: GND; TestPoint_Pad_1.5x1.5mm
TP6: SW_5V; TestPoint_Pad_1.5x1.5mm
TP7: I2C_SDA; TestPoint_Pad_1.5x1.5mm
TP8: I2C_SCL; TestPoint_Pad_1.5x1.5mm
TP9: FAN_SW; TestPoint_Pad_1.5x1.5mm
TP10: DIM1; TestPoint_Pad_1.5x1.5mm
TP11: LED_A33; TestPoint_Pad_1.5x1.5mm
TP12: LED_K33; TestPoint_Pad_1.5x1.5mm
U101: PCA9685PW (0x40); TSSOP-28_4.4x9.7mm_P0.65mm; LCSC C2678753
U102: PCA9685PW (0x41); TSSOP-28_4.4x9.7mm_P0.65mm; LCSC C2678753
U103: PCA9685PW (0x42); TSSOP-28_4.4x9.7mm_P0.65mm; LCSC C2678753
U104: PCA9685PW (0x43); TSSOP-28_4.4x9.7mm_P0.65mm; LCSC C2678753
U105: PCA9685PW (0x44); TSSOP-28_4.4x9.7mm_P0.65mm; LCSC C2678753
U106: PCA9685PW (0x45); TSSOP-28_4.4x9.7mm_P0.65mm; LCSC C2678753
U110: XL1509-5.0E1; SOIC-8_3.9x4.9mm_P1.27mm; LCSC C61063
U111: ADS1115IDGS (DNP); TSSOP-10_3x3mm_P0.5mm; LCSC C37593; not fitted

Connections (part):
+3.3V: C121.1, C122.1, C123.1, C124.1, C125.1, C126.1, J9.1, J10.1, R210.2, R211.2, TP3.1 (1_1), U101.28 (VDD), U102.1 (A0), U102.28 (VDD), U103.2 (A1), U103.28 (VDD), U104.1 (A0), U104.2 (A1), U104.28 (VDD), U105.3 (A2), U105.28 (VDD), U106.1 (A0), U106.3 (A2), U106.28 (VDD), U111.8 (VDD)
+5V: C111.1, J10.19, L101.2, R203.1, TP2.1 (1_1), U110.3 (FB)
+24V: C101.1, C102.1, C103.1, C104.1, C110.1, D102.1 (K), J7.1, J8.1, J12.1, TP1.1 (1_1), U110.1 (VIN); also elsewhere on the board
/BTN_DOWN: J10.10, SW3.1 (A), SW3.2 (B)
/BTN_MODE: J10.12, SW1.1 (A), SW1.2 (B)
/BTN_UP: J10.11, SW2.1 (A), SW2.2 (B)
/DIM1: TP10.1 (1_1), U101.9 (LED3); also elsewhere on the board
/DIM2: U101.8 (LED2); also elsewhere on the board
/DIM3: U101.7 (LED1); also elsewhere on the board
/DIM4: U101.6 (LED0); also elsewhere on the board
/DIM5: U104.10 (LED4); also elsewhere on the board
/DIM6: U104.9 (LED3); also elsewhere on the board
/DIM7: U104.8 (LED2); also elsewhere on the board
/DIM8: U104.7 (LED1); also elsewhere on the board
/DIM9: U104.6 (LED0); also elsewhere on the board
/DIM10: U105.8 (LED2); also elsewhere on the board
/DIM11: U105.7 (LED1); also elsewhere on the board
/DIM12: U105.6 (LED0); also elsewhere on the board
/DIM13: U101.13 (LED7); also elsewhere on the board
/DIM14: U101.12 (LED6); also elsewhere on the board
/DIM15: U101.11 (LED5); also elsewhere on the board
/DIM16: U101.10 (LED4); also elsewhere on the board
/DIM17: U104.15 (LED8); also elsewhere on the board
/DIM18: U104.13 (LED7); also elsewhere on the board
/DIM19: U104.12 (LED6); also elsewhere on the board
/DIM20: U104.11 (LED5); also elsewhere on the board
/DIM21: U105.12 (LED6); also elsewhere on the board
/DIM22: U105.11 (LED5); also elsewhere on the board
/DIM23: U105.10 (LED4); also elsewhere on the board
/DIM24: U105.9 (LED3); also elsewhere on the board
/DIM25: U101.18 (LED11); also elsewhere on the board
/DIM26: U101.17 (LED10); also elsewhere on the board
/DIM27: U101.16 (LED9); also elsewhere on the board
/DIM28: U101.15 (LED8); also elsewhere on the board
/DIM29: U104.19 (LED12); also elsewhere on the board
/DIM30: U104.18 (LED11); also elsewhere on the board
/DIM31: U104.17 (LED10); also elsewhere on the board
/DIM32: U104.16 (LED9); also elsewhere on the board
/DIM33: U105.17 (LED10); also elsewhere on the board
/DIM34: U105.16 (LED9); also elsewhere on the board
/DIM35: U105.15 (LED8); also elsewhere on the board
/DIM36: U105.13 (LED7); also elsewhere on the board
/DIM37: U101.22 (LED15); also elsewhere on the board
/DIM38: U101.21 (LED14); also elsewhere on the board
/DIM39: U101.20 (LED13); also elsewhere on the board
/DIM40: U101.19 (LED12); also elsewhere on the board
/DIM41: U104.22 (LED15); also elsewhere on the board
/DIM42: U104.21 (LED14); also elsewhere on the board
/DIM43: U104.20 (LED13); also elsewhere on the board
/DIM44: U105.22 (LED15); also elsewhere on the board
/DIM45: U105.21 (LED14); also elsewhere on the board
/DIM46: U105.20 (LED13); also elsewhere on the board
/DIM47: U105.19 (LED12); also elsewhere on the board
/DIM48: U105.18 (LED11); also elsewhere on the board
/DIM49: U102.9 (LED3); also elsewhere on the board
/DIM50: U102.8 (LED2); also elsewhere on the board
/DIM51: U102.7 (LED1); also elsewhere on the board
/DIM52: U102.6 (LED0); also elsewhere on the board
/DIM53: U103.8 (LED2); also elsewhere on the board
/DIM54: U103.7 (LED1); also elsewhere on the board
/DIM55: U103.6 (LED0); also elsewhere on the board
/DIM56: U106.10 (LED4); also elsewhere on the board
/DIM57: U106.9 (LED3); also elsewhere on the board
/DIM58: U106.8 (LED2); also elsewhere on the board
/DIM59: U106.7 (LED1); also elsewhere on the board
/DIM60: U106.6 (LED0); also elsewhere on the board
/DIM61: U102.13 (LED7); also elsewhere on the board
/DIM62: U102.12 (LED6); also elsewhere on the board
/DIM63: U102.11 (LED5); also elsewhere on the board
/DIM64: U102.10 (LED4); also elsewhere on the board
/DIM65: U103.12 (LED6); also elsewhere on the board
/DIM66: U103.11 (LED5); also elsewhere on the board
/DIM67: U103.10 (LED4); also elsewhere on the board
/DIM68: U103.9 (LED3); also elsewhere on the board
/DIM69: U106.15 (LED8); also elsewhere on the board
/DIM70: U106.13 (LED7); also elsewhere on the board
/DIM71: U106.12 (LED6); also elsewhere on the board
/DIM72: U106.11 (LED5); also elsewhere on the board
/DIM73: U102.18 (LED11); also elsewhere on the board
/DIM74: U102.17 (LED10); also elsewhere on the board
/DIM75: U102.16 (LED9); also elsewhere on the board
/DIM76: U102.15 (LED8); also elsewhere on the board
/DIM77: U103.17 (LED10); also elsewhere on the board
/DIM78: U103.16 (LED9); also elsewhere on the board
/DIM79: U103.15 (LED8); also elsewhere on the board
/DIM80: U103.13 (LED7); also elsewhere on the board
/DIM81: U106.19 (LED12); also elsewhere on the board
/DIM82: U106.18 (LED11); also elsewhere on the board
/DIM83: U106.17 (LED10); also elsewhere on the board
/DIM84: U106.16 (LED9); also elsewhere on the board
/DIM85: U102.22 (LED15); also elsewhere on the board
/DIM86: U102.21 (LED14); also elsewhere on the board
/DIM87: U102.20 (LED13); also elsewhere on the board
/DIM88: U102.19 (LED12); also elsewhere on the board
/DIM89: U103.22 (LED15); also elsewhere on the board
/DIM90: U103.21 (LED14); also elsewhere on the board
/DIM91: U103.20 (LED13); also elsewhere on the board
/DIM92: U103.19 (LED12); also elsewhere on the board
/DIM93: U103.18 (LED11); also elsewhere on the board
/DIM94: U106.22 (LED15); also elsewhere on the board
/DIM95: U106.21 (LED14); also elsewhere on the board
/DIM96: U106.20 (LED13); also elsewhere on the board
/FAN_G: Q1.1 (G), R201.2, R202.1
/FAN_PWM: J10.9, R201.1
/FAN_SW: D102.2 (A), J8.2, Q1.3 (D), TP9.1 (1_1)
/I2C_SCL: J11.3, R211.1, TP8.1 (1_1), U101.26 (SCL), U102.26 (SCL), U103.26 (SCL), U104.26 (SCL), U105.26 (SCL), U106.26 (SCL), U111.9 (SDA)
/I2C_SDA: J11.6, R210.1, TP7.1 (1_1), U101.27 (SDA), U102.27 (SDA), U103.27 (SDA), U104.27 (SDA), U105.27 (SDA), U106.27 (SDA), U111.10 (SCL)
/LED1_A: LED1.2 (A), R203.2
/LED2_A: LED2.2 (A), R204.2
/LED3_A: LED3.2 (A), R205.2
/LED_A1: J1.1; also elsewhere on the board
/LED_A2: J1.3; also elsewhere on the board
/LED_A3: J1.5; also elsewhere on the board
/LED_A4: J1.7; also elsewhere on the board
/LED_A5: J1.9; also elsewhere on the board
/LED_A6: J1.11; also elsewhere on the board
/LED_A7: J1.13; also elsewhere on the board
/LED_A8: J1.15; also elsewhere on the board
/LED_A9: J1.17; also elsewhere on the board
/LED_A10: J1.21; also elsewhere on the board
/LED_A11: J1.23; also elsewhere on the board
/LED_A12: J1.25; also elsewhere on the board
/LED_A13: J1.27; also elsewhere on the board
/LED_A14: J1.29; also elsewhere on the board
/LED_A15: J1.31; also elsewhere on the board
/LED_A16: J1.33; also elsewhere on the board
/LED_A17: J2.1; also elsewhere on the board
/LED_A18: J2.3; also elsewhere on the board
/LED_A19: J2.5; also elsewhere on the board
/LED_A20: J2.7; also elsewhere on the board
/LED_A21: J2.9; also elsewhere on the board
/LED_A22: J2.11; also elsewhere on the board
/LED_A23: J2.13; also elsewhere on the board
/LED_A24: J2.15; also elsewhere on the board
/LED_A25: J2.17; also elsewhere on the board
/LED_A26: J2.21; also elsewhere on the board
/LED_A27: J2.23; also elsewhere on the board
/LED_A28: J2.25; also elsewhere on the board
/LED_A29: J2.27; also elsewhere on the board
/LED_A30: J2.29; also elsewhere on the board
/LED_A31: J2.31; also elsewhere on the board
/LED_A32: J2.33; also elsewhere on the board
/LED_A33: J3.1, TP11.1 (1_1); also elsewhere on the board
/LED_A34: J3.3; also elsewhere on the board
/LED_A35: J3.5; also elsewhere on the board
/LED_A36: J3.7; also elsewhere on the board
/LED_A37: J3.9; also elsewhere on the board
/LED_A38: J3.11; also elsewhere on the board
/LED_A39: J3.13; also elsewhere on the board
/LED_A40: J3.15; also elsewhere on the board
/LED_A41: J3.17; also elsewhere on the board
/LED_A42: J3.21; also elsewhere on the board
/LED_A43: J3.23; also elsewhere on the board
/LED_A44: J3.25; also elsewhere on the board
/LED_A45: J3.27; also elsewhere on the board
/LED_A46: J3.29; also elsewhere on the board
/LED_A47: J3.31; also elsewhere on the board
/LED_A48: J3.33; also elsewhere on the board
/LED_A49: J4.1; also elsewhere on the board
/LED_A50: J4.3; also elsewhere on the board
/LED_A51: J4.5; also elsewhere on the board
/LED_A52: J4.7; also elsewhere on the board
/LED_A53: J4.9; also elsewhere on the board
/LED_A54: J4.11; also elsewhere on the board
/LED_A55: J4.13; also elsewhere on the board
/LED_A56: J4.15; also elsewhere on the board
/LED_A57: J4.17; also elsewhere on the board
/LED_A58: J4.21; also elsewhere on the board
/LED_A59: J4.23; also elsewhere on the board
/LED_A60: J4.25; also elsewhere on the board
/LED_A61: J4.27; also elsewhere on the board
/LED_A62: J4.29; also elsewhere on the board
/LED_A63: J4.31; also elsewhere on the board
/LED_A64: J4.33; also elsewhere on the board
/LED_A65: J5.1; also elsewhere on the board
/LED_A66: J5.3; also elsewhere on the board
/LED_A67: J5.5; also elsewhere on the board
/LED_A68: J5.7; also elsewhere on the board
/LED_A69: J5.9; also elsewhere on the board
/LED_A70: J5.11; also elsewhere on the board
/LED_A71: J5.13; also elsewhere on the board
/LED_A72: J5.15; also elsewhere on the board
/LED_A73: J5.17; also elsewhere on the board
/LED_A74: J5.21; also elsewhere on the board
/LED_A75: J5.23; also elsewhere on the board
/LED_A76: J5.25; also elsewhere on the board
/LED_A77: J5.27; also elsewhere on the board
/LED_A78: J5.29; also elsewhere on the board
/LED_A79: J5.31; also elsewhere on the board
/LED_A80: J5.33; also elsewhere on the board
/LED_A81: J6.1; also elsewhere on the board
/LED_A82: J6.3; also elsewhere on the board
/LED_A83: J6.5; also elsewhere on the board
/LED_A84: J6.7; also elsewhere on the board
/LED_A85: J6.9; also elsewhere on the board
/LED_A86: J6.11; also elsewhere on the board
/LED_A87: J6.13; also elsewhere on the board
/LED_A88: J6.15; also elsewhere on the board
/LED_A89: J6.17; also elsewhere on the board
/LED_A90: J6.21; also elsewhere on the board
/LED_A91: J6.23; also elsewhere on the board
/LED_A92: J6.25; also elsewhere on the board
/LED_A93: J6.27; also elsewhere on the board
/LED_A94: J6.29; also elsewhere on the board
/LED_A95: J6.31; also elsewhere on the board
/LED_A96: J6.33; also elsewhere on the board
/LED_FAULT: J10.15, R205.1
/LED_K1: J1.2; also elsewhere on the board
/LED_K2: J1.4; also elsewhere on the board
/LED_K3: J1.6; also elsewhere on the board
/LED_K4: J1.8; also elsewhere on the board
/LED_K5: J1.10; also elsewhere on the board
/LED_K6: J1.12; also elsewhere on the board
/LED_K7: J1.14; also elsewhere on the board
/LED_K8: J1.16; also elsewhere on the board
/LED_K9: J1.18; also elsewhere on the board
/LED_K10: J1.22; also elsewhere on the board
/LED_K11: J1.24; also elsewhere on the board
/LED_K12: J1.26; also elsewhere on the board
/LED_K13: J1.28; also elsewhere on the board
/LED_K14: J1.30; also elsewhere on the board
/LED_K15: J1.32; also elsewhere on the board
/LED_K16: J1.34; also elsewhere on the board
/LED_K17: J2.2; also elsewhere on the board
/LED_K18: J2.4; also elsewhere on the board
/LED_K19: J2.6; also elsewhere on the board
/LED_K20: J2.8; also elsewhere on the board
/LED_K21: J2.10; also elsewhere on the board
/LED_K22: J2.12; also elsewhere on the board
/LED_K23: J2.14; also elsewhere on the board
/LED_K24: J2.16; also elsewhere on the board
/LED_K25: J2.18; also elsewhere on the board
/LED_K26: J2.22; also elsewhere on the board
/LED_K27: J2.24; also elsewhere on the board
/LED_K28: J2.26; also elsewhere on the board
/LED_K29: J2.28; also elsewhere on the board
/LED_K30: J2.30; also elsewhere on the board
/LED_K31: J2.32; also elsewhere on the board
/LED_K32: J2.34; also elsewhere on the board
/LED_K33: J3.2, TP12.1 (1_1); also elsewhere on the board
/LED_K34: J3.4; also elsewhere on the board
/LED_K35: J3.6; also elsewhere on the board
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

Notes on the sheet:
96 DRIVER CHANNELS - see channel.kicad_sch
PCA9685 PWM BANK 0x40-0x45
5V RAIL + 24V INPUT
FAN
ESP32 DEVKITC-38 SOCKET (J10 left / J11 right, pin1 = 3V3/GND end)
RIBBONS TO LED BOARD

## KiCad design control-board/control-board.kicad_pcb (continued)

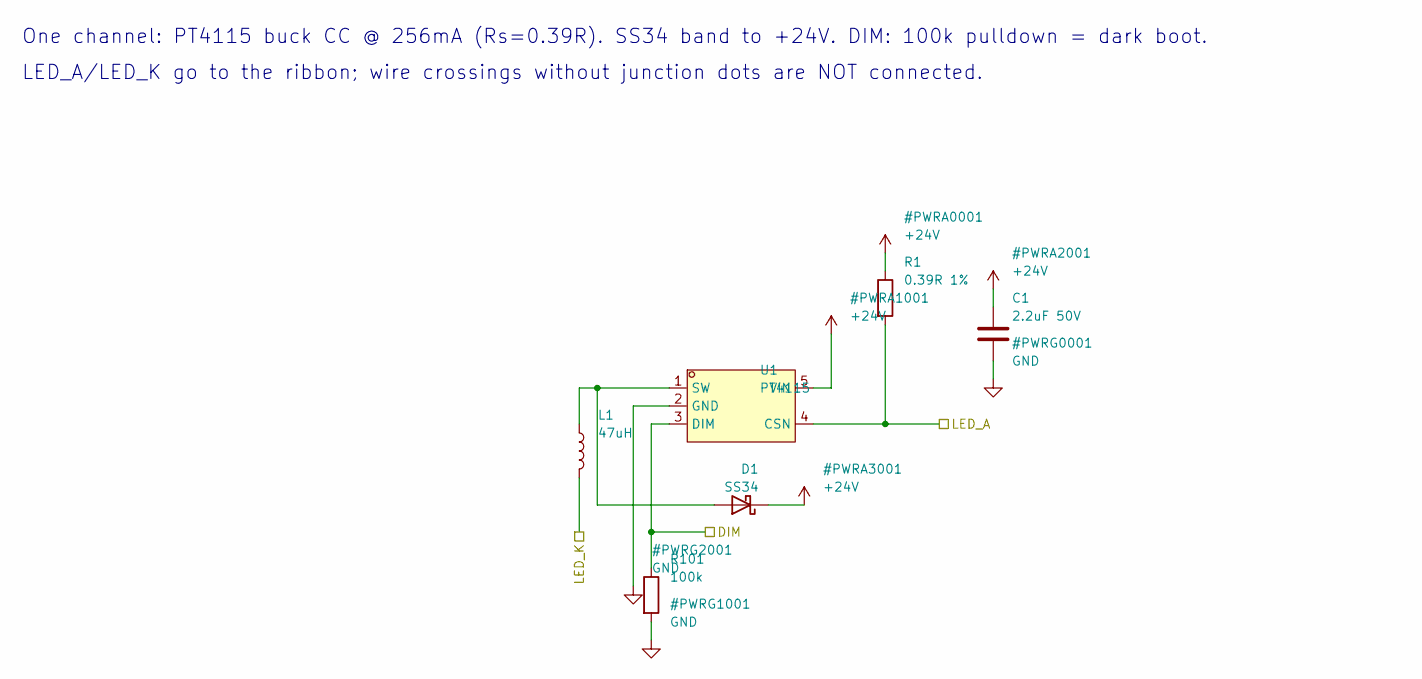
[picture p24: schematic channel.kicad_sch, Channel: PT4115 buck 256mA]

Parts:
C1: 2.2uF 50V; C_0805_2012Metric; LCSC C125847
D1: SS34; D_SMA; LCSC C8678
L1: 47uH; L_Sunlord_SWPA4030S; LCSC C54731
R1: 0.39R 1%; R_0805_2012Metric; LCSC C2930218
R101: 100k; R_0603_1608Metric; LCSC C25803
U1: PT4115; SOT-89-5_L4.5-W2.5-P1.50-LS4.5-BR; LCSC C347356

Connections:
+24V: C1.1, D1.1 (K), R1.1, U1.5 (VIN); also elsewhere on the board
/DIM1: R101.1, U1.3 (DIM); also elsewhere on the board
/LED_A33: R1.2, U1.4 (CSN); also elsewhere on the board
/LED_K33: L1.2; also elsewhere on the board
GND: C1.2, R101.2, U1.2 (GND); also elsewhere on the board
unnamed: D1.2 (A), L1.1, U1.1 (SW)

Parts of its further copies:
C2, C3, C4, C5, C6, C7, C8, C9, C10, C11, C12, C13, C14, C15, C16, C17, C18, C19, C20, C21, C22, C23, C24, C25, C26, C27, C28, C29, C30, C31, C32, C33, C34, C35, C36, C37, C38, C39, C40, C41, C42, C43, C44, C45, C46, C47, C48, C49, C50, C51, C52, C53, C54, C55, C56, C57, C58, C59, C60, C61, C62, C63, C64, C65, C66, C67, C68, C69, C70, C71, C72, C73, C74, C75, C76, C77, C78, C79, C80, C81, C82, C83, C84, C85, C86, C87, C88, C89, C90, C91, C92, C93, C94, C95, C96: 2.2uF 50V; C_0805_2012Metric; LCSC C125847
D2, D3, D4, D5, D6, D7, D8, D9, D10, D11, D12, D13, D14, D15, D16, D17, D18, D19, D20, D21, D22, D23, D24, D25, D26, D27, D28, D29, D30, D31, D32, D33, D34, D35, D36, D37, D38, D39, D40, D41, D42, D43, D44, D45, D46, D47, D48, D49, D50, D51, D52, D53, D54, D55, D56, D57, D58, D59, D60, D61, D62, D63, D64, D65, D66, D67, D68, D69, D70, D71, D72, D73, D74, D75, D76, D77, D78, D79, D80, D81, D82, D83, D84, D85, D86, D87, D88, D89, D90, D91, D92, D93, D94, D95, D96: SS34; D_SMA; LCSC C8678
L2, L3, L4, L5, L6, L7, L8, L9, L10, L11, L12, L13, L14, L15, L16, L17, L18, L19, L20, L21, L22, L23, L24, L25, L26, L27, L28, L29, L30, L31, L32, L33, L34, L35, L36, L37, L38, L39, L40, L41, L42, L43, L44, L45, L46, L47, L48, L49, L50, L51, L52, L53, L54, L55, L56, L57, L58, L59, L60, L61, L62, L63, L64, L65, L66, L67, L68, L69, L70, L71, L72, L73, L74, L75, L76, L77, L78, L79, L80, L81, L82, L83, L84, L85, L86, L87, L88, L89, L90, L91, L92, L93, L94, L95, L96: 47uH; L_Sunlord_SWPA4030S; LCSC C54731
R2, R3, R4, R5, R6, R7, R8, R9, R10, R11, R12, R13, R14, R15, R16, R17, R18, R19, R20, R21, R22, R23, R24, R25, R26, R27, R28, R29, R30, R31, R32, R33, R34, R35, R36, R37, R38, R39, R40, R41, R42, R43, R44, R45, R46, R47, R48, R49, R50, R51, R52, R53, R54, R55, R56, R57, R58, R59, R60, R61, R62, R63, R64, R65, R66, R67, R68, R69, R70, R71, R72, R73, R74, R75, R76, R77, R78, R79, R80, R81, R82, R83, R84, R85, R86, R87, R88, R89, R90, R91, R92, R93, R94, R95, R96: 0.39R 1%; R_0805_2012Metric; LCSC C2930218
R102, R103, R104, R105, R106, R107, R108, R109, R110, R111, R112, R113, R114, R115, R116, R117, R118, R119, R120, R121, R122, R123, R124, R125, R126, R127, R128, R129, R130, R131, R132, R133, R134, R135, R136, R137, R138, R139, R140, R141, R142, R143, R144, R145, R146, R147, R148, R149, R150, R151, R152, R153, R154, R155, R156, R157, R158, R159, R160, R161, R162, R163, R164, R165, R166, R167, R168, R169, R170, R171, R172, R173, R174, R175, R176, R177, R178, R179, R180, R181, R182, R183, R184, R185, R186, R187, R188, R189, R190, R191, R192, R193, R194, R195, R196: 100k; R_0603_1608Metric; LCSC C25803
U2, U3, U4, U5, U6, U7, U8, U9, U10, U11, U12, U13, U14, U15, U16, U17, U18, U19, U20, U21, U22, U23, U24, U25, U26, U27, U28, U29, U30, U31, U32, U33, U34, U35, U36, U37, U38, U39, U40, U41, U42, U43, U44, U45, U46, U47, U48, U49, U50, U51, U52, U53, U54, U55, U56, U57, U58, U59, U60, U61, U62, U63, U64, U65, U66, U67, U68, U69, U70, U71, U72, U73, U74, U75, U76, U77, U78, U79, U80, U81, U82, U83, U84, U85, U86, U87, U88, U89, U90, U91, U92, U93, U94, U95, U96: PT4115; SOT-89-5_L4.5-W2.5-P1.50-LS4.5-BR; LCSC C347356

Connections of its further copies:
+24V: C2.1, C3.1, C4.1, C5.1, C6.1, C7.1, C8.1, C9.1, C10.1, C11.1, C12.1, C13.1, C14.1, C15.1, C16.1, C17.1, C18.1, C19.1, C20.1, C21.1, C22.1, C23.1, C24.1, C25.1, C26.1, C27.1, C28.1, C29.1, C30.1, C31.1, C32.1, C33.1, C34.1, C35.1, C36.1, C37.1, C38.1, C39.1, C40.1, C41.1, C42.1, C43.1, C44.1, C45.1, C46.1, C47.1, C48.1, C49.1, C50.1, C51.1, C52.1, C53.1, C54.1, C55.1, C56.1, C57.1, C58.1, C59.1, C60.1, C61.1, C62.1, C63.1, C64.1, C65.1, C66.1, C67.1, C68.1, C69.1, C70.1, C71.1, C72.1, C73.1, C74.1, C75.1, C76.1, C77.1, C78.1, C79.1, C80.1, C81.1, C82.1, C83.1, C84.1, C85.1, C86.1, C87.1, C88.1, C89.1, C90.1, C91.1, C92.1, C93.1, C94.1, C95.1, C96.1, D2.1 (K), D3.1 (K), D4.1 (K), D5.1 (K), D6.1 (K), D7.1 (K), D8.1 (K), D9.1 (K), D10.1 (K), D11.1 (K), D12.1 (K), D13.1 (K), D14.1 (K), D15.1 (K), D16.1 (K), D17.1 (K), D18.1 (K), D19.1 (K), D20.1 (K), D21.1 (K), D22.1 (K), D23.1 (K), D24.1 (K), D25.1 (K), D26.1 (K), D27.1 (K), D28.1 (K), D29.1 (K), D30.1 (K), D31.1 (K), D32.1 (K), D33.1 (K), D34.1 (K), D35.1 (K), D36.1 (K), D37.1 (K), D38.1 (K), D39.1 (K), D40.1 (K), D41.1 (K), D42.1 (K), D43.1 (K), D44.1 (K), D45.1 (K), D46.1 (K), D47.1 (K), D48.1 (K), D49.1 (K), D50.1 (K), D51.1 (K), D52.1 (K), D53.1 (K), D54.1 (K), D55.1 (K), D56.1 (K), D57.1 (K), D58.1 (K), D59.1 (K), D60.1 (K), D61.1 (K), D62.1 (K), D63.1 (K), D64.1 (K), D65.1 (K), D66.1 (K), D67.1 (K), D68.1 (K), D69.1 (K), D70.1 (K), D71.1 (K), D72.1 (K), D73.1 (K), D74.1 (K), D75.1 (K), D76.1 (K), D77.1 (K), D78.1 (K), D79.1 (K), D80.1 (K), D81.1 (K), D82.1 (K), D83.1 (K), D84.1 (K), D85.1 (K), D86.1 (K), D87.1 (K), D88.1 (K), D89.1 (K), D90.1 (K), D91.1 (K), D92.1 (K), D93.1 (K), D94.1 (K), D95.1 (K), D96.1 (K), R2.1, R3.1, R4.1, R5.1, R6.1, R7.1, R8.1, R9.1, R10.1, R11.1, R12.1, R13.1, R14.1, R15.1, R16.1, R17.1, R18.1, R19.1, R20.1, R21.1, R22.1, R23.1, R24.1, R25.1, R26.1, R27.1, R28.1, R29.1, R30.1, R31.1, R32.1, R33.1, R34.1, R35.1, R36.1, R37.1, R38.1, R39.1, R40.1, R41.1, R42.1, R43.1, R44.1, R45.1, R46.1, R47.1, R48.1, R49.1, R50.1, R51.1, R52.1, R53.1, R54.1, R55.1, R56.1, R57.1, R58.1, R59.1, R60.1, R61.1, R62.1, R63.1, R64.1, R65.1, R66.1, R67.1, R68.1, R69.1, R70.1, R71.1, R72.1, R73.1, R74.1, R75.1, R76.1, R77.1, R78.1, R79.1, R80.1, R81.1, R82.1, R83.1, R84.1, R85.1, R86.1, R87.1, R88.1, R89.1, R90.1, R91.1, R92.1, R93.1, R94.1, R95.1, R96.1, U2.5 (VIN), U3.5 (VIN), U4.5 (VIN), U5.5 (VIN), U6.5 (VIN), U7.5 (VIN), U8.5 (VIN), U9.5 (VIN), U10.5 (VIN), U11.5 (VIN), U12.5 (VIN), U13.5 (VIN), U14.5 (VIN), U15.5 (VIN), U16.5 (VIN), U17.5 (VIN), U18.5 (VIN), U19.5 (VIN), U20.5 (VIN), U21.5 (VIN), U22.5 (VIN), U23.5 (VIN), U24.5 (VIN), U25.5 (VIN), U26.5 (VIN), U27.5 (VIN), U28.5 (VIN), U29.5 (VIN), U30.5 (VIN), U31.5 (VIN), U32.5 (VIN), U33.5 (VIN), U34.5 (VIN), U35.5 (VIN), U36.5 (VIN), U37.5 (VIN), U38.5 (VIN), U39.5 (VIN), U40.5 (VIN), U41.5 (VIN), U42.5 (VIN), U43.5 (VIN), U44.5 (VIN), U45.5 (VIN), U46.5 (VIN), U47.5 (VIN), U48.5 (VIN), U49.5 (VIN), U50.5 (VIN), U51.5 (VIN), U52.5 (VIN), U53.5 (VIN), U54.5 (VIN), U55.5 (VIN), U56.5 (VIN), U57.5 (VIN), U58.5 (VIN), U59.5 (VIN), U60.5 (VIN), U61.5 (VIN), U62.5 (VIN), U63.5 (VIN), U64.5 (VIN), U65.5 (VIN), U66.5 (VIN), U67.5 (VIN), U68.5 (VIN), U69.5 (VIN), U70.5 (VIN), U71.5 (VIN), U72.5 (VIN), U73.5 (VIN), U74.5 (VIN), U75.5 (VIN), U76.5 (VIN), U77.5 (VIN), U78.5 (VIN), U79.5 (VIN), U80.5 (VIN), U81.5 (VIN), U82.5 (VIN), U83.5 (VIN), U84.5 (VIN), U85.5 (VIN), U86.5 (VIN), U87.5 (VIN), U88.5 (VIN), U89.5 (VIN), U90.5 (VIN), U91.5 (VIN), U92.5 (VIN), U93.5 (VIN), U94.5 (VIN), U95.5 (VIN), U96.5 (VIN); also elsewhere on the board
/DIM2: R102.1, U2.3 (DIM); also elsewhere on the board
/DIM3: R103.1, U3.3 (DIM); also elsewhere on the board
/DIM4: R104.1, U4.3 (DIM); also elsewhere on the board
/DIM5: R105.1, U5.3 (DIM); also elsewhere on the board
/DIM6: R106.1, U6.3 (DIM); also elsewhere on the board
/DIM7: R107.1, U7.3 (DIM); also elsewhere on the board
/DIM8: R108.1, U8.3 (DIM); also elsewhere on the board
/DIM9: R109.1, U9.3 (DIM); also elsewhere on the board
/DIM10: R110.1, U10.3 (DIM); also elsewhere on the board
/DIM11: R111.1, U11.3 (DIM); also elsewhere on the board
/DIM12: R112.1, U12.3 (DIM); also elsewhere on the board
/DIM13: R113.1, U13.3 (DIM); also elsewhere on the board
/DIM14: R114.1, U14.3 (DIM); also elsewhere on the board
/DIM15: R115.1, U15.3 (DIM); also elsewhere on the board
/DIM16: R116.1, U16.3 (DIM); also elsewhere on the board
/DIM17: R117.1, U17.3 (DIM); also elsewhere on the board
/DIM18: R118.1, U18.3 (DIM); also elsewhere on the board
/DIM19: R119.1, U19.3 (DIM); also elsewhere on the board
/DIM20: R120.1, U20.3 (DIM); also elsewhere on the board
/DIM21: R121.1, U21.3 (DIM); also elsewhere on the board
/DIM22: R122.1, U22.3 (DIM); also elsewhere on the board
/DIM23: R123.1, U23.3 (DIM); also elsewhere on the board
/DIM24: R124.1, U24.3 (DIM); also elsewhere on the board
/DIM25: R125.1, U25.3 (DIM); also elsewhere on the board
/DIM26: R126.1, U26.3 (DIM); also elsewhere on the board
/DIM27: R127.1, U27.3 (DIM); also elsewhere on the board
/DIM28: R128.1, U28.3 (DIM); also elsewhere on the board
/DIM29: R129.1, U29.3 (DIM); also elsewhere on the board
/DIM30: R130.1, U30.3 (DIM); also elsewhere on the board
/DIM31: R131.1, U31.3 (DIM); also elsewhere on the board
/DIM32: R132.1, U32.3 (DIM); also elsewhere on the board
/DIM33: R133.1, U33.3 (DIM); also elsewhere on the board
/DIM34: R134.1, U34.3 (DIM); also elsewhere on the board
/DIM35: R135.1, U35.3 (DIM); also elsewhere on the board
/DIM36: R136.1, U36.3 (DIM); also elsewhere on the board
/DIM37: R137.1, U37.3 (DIM); also elsewhere on the board
/DIM38: R138.1, U38.3 (DIM); also elsewhere on the board
/DIM39: R139.1, U39.3 (DIM); also elsewhere on the board
/DIM40: R140.1, U40.3 (DIM); also elsewhere on the board
/DIM41: R141.1, U41.3 (DIM); also elsewhere on the board
/DIM42: R142.1, U42.3 (DIM); also elsewhere on the board
/DIM43: R143.1, U43.3 (DIM); also elsewhere on the board
/DIM44: R144.1, U44.3 (DIM); also elsewhere on the board
/DIM45: R145.1, U45.3 (DIM); also elsewhere on the board
/DIM46: R146.1, U46.3 (DIM); also elsewhere on the board
/DIM47: R147.1, U47.3 (DIM); also elsewhere on the board
/DIM48: R148.1, U48.3 (DIM); also elsewhere on the board
/DIM49: R149.1, U49.3 (DIM); also elsewhere on the board
/DIM50: R150.1, U50.3 (DIM); also elsewhere on the board
/DIM51: R151.1, U51.3 (DIM); also elsewhere on the board
/DIM52: R152.1, U52.3 (DIM); also elsewhere on the board
/DIM53: R153.1, U53.3 (DIM); also elsewhere on the board
/DIM54: R154.1, U54.3 (DIM); also elsewhere on the board
/DIM55: R155.1, U55.3 (DIM); also elsewhere on the board
/DIM56: R156.1, U56.3 (DIM); also elsewhere on the board
/DIM57: R157.1, U57.3 (DIM); also elsewhere on the board
/DIM58: R158.1, U58.3 (DIM); also elsewhere on the board
/DIM59: R159.1, U59.3 (DIM); also elsewhere on the board
/DIM60: R160.1, U60.3 (DIM); also elsewhere on the board
/DIM61: R161.1, U61.3 (DIM); also elsewhere on the board
/DIM62: R162.1, U62.3 (DIM); also elsewhere on the board
/DIM63: R163.1, U63.3 (DIM); also elsewhere on the board
/DIM64: R164.1, U64.3 (DIM); also elsewhere on the board
/DIM65: R165.1, U65.3 (DIM); also elsewhere on the board
/DIM66: R166.1, U66.3 (DIM); also elsewhere on the board
/DIM67: R167.1, U67.3 (DIM); also elsewhere on the board
/DIM68: R168.1, U68.3 (DIM); also elsewhere on the board
/DIM69: R169.1, U69.3 (DIM); also elsewhere on the board
/DIM70: R170.1, U70.3 (DIM); also elsewhere on the board
/DIM71: R171.1, U71.3 (DIM); also elsewhere on the board
/DIM72: R172.1, U72.3 (DIM); also elsewhere on the board
/DIM73: R173.1, U73.3 (DIM); also elsewhere on the board
/DIM74: R174.1, U74.3 (DIM); also elsewhere on the board
/DIM75: R175.1, U75.3 (DIM); also elsewhere on the board
/DIM76: R176.1, U76.3 (DIM); also elsewhere on the board
/DIM77: R177.1, U77.3 (DIM); also elsewhere on the board
/DIM78: R178.1, U78.3 (DIM); also elsewhere on the board
/DIM79: R179.1, U79.3 (DIM); also elsewhere on the board
/DIM80: R180.1, U80.3 (DIM); also elsewhere on the board
/DIM81: R181.1, U81.3 (DIM); also elsewhere on the board
/DIM82: R182.1, U82.3 (DIM); also elsewhere on the board
/DIM83: R183.1, U83.3 (DIM); also elsewhere on the board
/DIM84: R184.1, U84.3 (DIM); also elsewhere on the board
/DIM85: R185.1, U85.3 (DIM); also elsewhere on the board
/DIM86: R186.1, U86.3 (DIM); also elsewhere on the board
/DIM87: R187.1, U87.3 (DIM); also elsewhere on the board
/DIM88: R188.1, U88.3 (DIM); also elsewhere on the board
/DIM89: R189.1, U89.3 (DIM); also elsewhere on the board
/DIM90: R190.1, U90.3 (DIM); also elsewhere on the board
/DIM91: R191.1, U91.3 (DIM); also elsewhere on the board
/DIM92: R192.1, U92.3 (DIM); also elsewhere on the board
/DIM93: R193.1, U93.3 (DIM); also elsewhere on the board
/DIM94: R194.1, U94.3 (DIM); also elsewhere on the board
/DIM95: R195.1, U95.3 (DIM); also elsewhere on the board
/DIM96: R196.1, U96.3 (DIM); also elsewhere on the board
/LED_A1: R10.2, U10.4 (CSN); also elsewhere on the board
/LED_A2: R11.2, U11.4 (CSN); also elsewhere on the board
/LED_A3: R12.2, U12.4 (CSN); also elsewhere on the board
/LED_A4: R21.2, U21.4 (CSN); also elsewhere on the board
/LED_A5: R22.2, U22.4 (CSN); also elsewhere on the board
/LED_A6: R23.2, U23.4 (CSN); also elsewhere on the board
/LED_A7: R24.2, U24.4 (CSN); also elsewhere on the board
/LED_A8: R33.2, U33.4 (CSN); also elsewhere on the board
/LED_A9: R34.2, U34.4 (CSN); also elsewhere on the board
/LED_A10: R35.2, U35.4 (CSN); also elsewhere on the board
/LED_A11: R36.2, U36.4 (CSN); also elsewhere on the board
/LED_A12: R44.2, U44.4 (CSN); also elsewhere on the board
/LED_A13: R45.2, U45.4 (CSN); also elsewhere on the board
/LED_A14: R46.2, U46.4 (CSN); also elsewhere on the board
/LED_A15: R47.2, U47.4 (CSN); also elsewhere on the board
/LED_A16: R48.2, U48.4 (CSN); also elsewhere on the board
/LED_A17: R5.2, U5.4 (CSN); also elsewhere on the board
/LED_A18: R6.2, U6.4 (CSN); also elsewhere on the board
/LED_A19: R17.2, U17.4 (CSN); also elsewhere on the board
/LED_A20: R7.2, U7.4 (CSN); also elsewhere on the board
/LED_A21: R18.2, U18.4 (CSN); also elsewhere on the board
/LED_A22: R29.2, U29.4 (CSN); also elsewhere on the board
/LED_A23: R41.2, U41.4 (CSN); also elsewhere on the board
/LED_A24: R30.2, U30.4 (CSN); also elsewhere on the board
/LED_A25: R19.2, U19.4 (CSN); also elsewhere on the board
/LED_A26: R8.2, U8.4 (CSN); also elsewhere on the board
/LED_A27: R42.2, U42.4 (CSN); also elsewhere on the board
/LED_A28: R9.2, U9.4 (CSN); also elsewhere on the board
/LED_A29: R31.2, U31.4 (CSN); also elsewhere on the board
/LED_A30: R20.2, U20.4 (CSN); also elsewhere on the board
/LED_A31: R43.2, U43.4 (CSN); also elsewhere on the board
/LED_A32: R32.2, U32.4 (CSN); also elsewhere on the board
/LED_A34: R13.2, U13.4 (CSN); also elsewhere on the board
/LED_A35: R2.2, U2.4 (CSN); also elsewhere on the board
/LED_A36: R25.2, U25.4 (CSN); also elsewhere on the board
/LED_A37: R14.2, U14.4 (CSN); also elsewhere on the board
/LED_A38: R37.2, U37.4 (CSN); also elsewhere on the board
/LED_A39: R26.2, U26.4 (CSN); also elsewhere on the board
/LED_A40: R38.2, U38.4 (CSN); also elsewhere on the board
/LED_A41: R3.2, U3.4 (CSN); also elsewhere on the board
/LED_A42: R15.2, U15.4 (CSN); also elsewhere on the board
/LED_A43: R27.2, U27.4 (CSN); also elsewhere on the board
/LED_A44: R4.2, U4.4 (CSN); also elsewhere on the board
/LED_A45: R16.2, U16.4 (CSN); also elsewhere on the board
/LED_A46: R39.2, U39.4 (CSN); also elsewhere on the board
/LED_A47: R28.2, U28.4 (CSN); also elsewhere on the board
/LED_A48: R40.2, U40.4 (CSN); also elsewhere on the board
/LED_A49: R57.2, U57.4 (CSN); also elsewhere on the board
/LED_A50: R59.2, U59.4 (CSN); also elsewhere on the board
/LED_A51: R60.2, U60.4 (CSN); also elsewhere on the board
/LED_A52: R58.2, U58.4 (CSN); also elsewhere on the board
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

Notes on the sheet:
One channel: PT4115 buck CC @ 256mA (Rs=0.39R). SS34 band to +24V. DIM: 100k pulldown = dark boot.
LED_A/LED_K go to the ribbon; wire crossings without junction dots are NOT connected.

Board: 4 copper layers, 641 parts (0 on the bottom side), 412 nets, no tracks yet.

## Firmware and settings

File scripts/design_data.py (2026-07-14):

"""Single source of truth for the 12x8 LED array design.

Both boards' parts, positions, and nets are defined here.
- gen_schematics.py consumes SCH positions (mm, y-down, 1.27 grid)
- gen_pcbs.py consumes PCB positions (mm) and rotations
- gen_outputs.py consumes parts + nets for BOM/CPL/CONNECTIONS.md

Channel numbering: n = (row-1)*12 + col, row 1..8 top->bottom, col 1..12 left->right.
"""

# ---------------------------------------------------------------- helpers

def snap(v, g=1.27):
    return round(round(v / g) * g, 3)


def part(ref, lib_id, value, footprint, lcsc, sch_xy, pcb_xy, pcb_rot=0.0,
         dnp=False, desc=""):
    return dict(ref=ref, lib_id=lib_id, value=value, footprint=footprint,
                lcsc=lcsc, sch_xy=(snap(sch_xy[0]), snap(sch_xy[1])),
                pcb_xy=pcb_xy, pcb_rot=pcb_rot, dnp=dnp, desc=desc)


def ch_rc(n):  # channel -> (row, col) 1-based
    return ((n - 1) // 12 + 1, (n - 1) % 12 + 1)


# Decoupled ribbon maps: a SLOT (connector Jk + IDE-safe pin-pair) is the
# logical channel.  Wells and drivers are assigned to slots independently
# (each board optimized on its own geometry); the cable wires slot->slot.
from pin_maps import WELL_CONN, DRV_CONN, NTC_MAP, PCA_MAP


def pair_pins(i):
    """IDE-safe pair index 1..16 -> (anode_pin, cathode_pin)."""
    return (2 * i - 1, 2 * i) if i <= 9 else (2 * i + 1, 2 * i + 2)


def slot2ch(conn_ref, anode_pin):
    """Ribbon slot (Jk, pinA) -> logical channel 1..96.  Same on both boards,
    so a well and a driver on the same slot share net LED_A<ch>/LED_K<ch>."""
    k = int(conn_ref[1:])
    a = anode_pin
    i = (a + 1) // 2 if a <= 17 else (a - 1) // 2
    return (k - 1) * 16 + i


def well_channel(w):
    """Logical channel carrying LED well w."""
    j, pa, pk = WELL_CONN[w]
    return slot2ch(j, pa)


def drv_channel(d):
    """Logical channel carrying driver d."""
    j, pa, pk = DRV_CONN[d]
    return slot2ch(j, pa)


# 4067 mux input pin numbers: I0..I7 = pins 9..2, I8..I15 = pins 23..16
MUX_INPUT_PIN = {k: 9 - k for k in range(8)}
MUX_INPUT_PIN.update({k: 31 - k for k in range(8, 16)})
# mux control pins (CD74HC4067M96): COM=1, S0=10, S1=11, S2=14, S3=13, /E=15,
# GND=12, VCC=24


def ntc_mux(n):
    """NTC n -> (mux_ref, input_pin) - side-matched to placement."""
    return NTC_MAP[n]


# J5 logic ribbon pinout (both boards)
J5_PINOUT = {
    1: "+3.3V", 2: "GND", 3: "NTC_SIG1", 4: "GND", 5: "NTC_SIG2", 6: "GND",
    7: "NTC_SIG3", 8: "GND", 9: "NTC_SIG4", 10: "GND", 11: "NTC_SIG5",
    12: "GND", 13: "NTC_SIG6", 14: "GND", 15: "MUX_A0", 16: "MUX_A1",
    17: "MUX_A2", 18: "MUX_A3", 19: "GND", 20: "GND",
}

# PCA9685PW pin map (TSSOP-28)
PCA_LED_PIN = {i: 6 + i for i in range(8)}          # LED0..LED7 = 6..13
PCA_LED_PIN.update({i: 7 + i for i in range(8, 16)})  # LED8..LED15 = 15..22
PCA_PINS = dict(A0=1, A1=2, A2=3, A3=4, A4=5, GND=14, OE=23, A5=24,
                EXTCLK=25, SCL=26, SDA=27, VDD=28)

# ESP32 DevKitC-38 socket map: J10 = left row seen from top (pin1 = 3V3 corner),
# J11 = right row (pin1 = GND corner, same end of board as J10 pin1).
ESP32_J10 = ["3V3", "EN", "GPIO36/VP", "GPIO39/VN", "GPIO34", "GPIO35",
             "GPIO32", "GPIO33", "GPIO25", "GPIO26", "GPIO27", "GPIO14",
             "GPIO12", "GND", "GPIO13", "GPIO9/D2", "GPIO10/D3", "GPIO11/CMD",
             "5V"]
ESP32_J11 = ["GND", "GPIO23", "GPIO22", "GPIO1/TX0", "GPIO3/RX0", "GPIO21",
             "GND", "GPIO19", "GPIO18", "GPIO5", "GPIO17", "GPIO16", "GPIO4",
             "GPIO0", "GPIO2", "GPIO15", "GPIO8/D1", "GPIO7/D0", "GPIO6/CLK"]

# GPIO assignments (see CONNECTIONS.md)
GPIO_PLAN = {
    "GPIO21": "I2C SDA (PCA9685 x6, ADS1115 opt.)",
    "GPIO22": "I2C SCL",
    "GPIO16": "MUX_A0", "GPIO17": "MUX_A1", "GPIO18": "MUX_A2",
    "GPIO19": "MUX_A3",
    "GPIO32": "NTC_SIG1 (ADC1_CH4)", "GPIO33": "NTC_SIG2 (ADC1_CH5)",
    "GPIO34": "NTC_SIG3 (ADC1_CH6)", "GPIO35": "NTC_SIG4 (ADC1_CH7)",
    "GPIO36/VP": "NTC_SIG5 (ADC1_CH0)", "GPIO39/VN": "NTC_SIG6 (ADC1_CH3)",
    "GPIO25": "FAN_PWM (Q1 gate via R201)",
    "GPIO4": "STATUS LED2 (blue)", "GPIO13": "FAULT LED3 (red)",
    "GPIO14": "SW1 MODE (to GND, internal pull-up)",
    "GPIO27": "SW2 UP (to GND, internal pull-up)",
    "GPIO26": "SW3 DOWN (to GND, internal pull-up)",
}

# ------------------------------------------------------------ footprints

FP = {
    "led":    "jlc_parts:LED-SMD_3P-L3.5-W3.5_NLW3535AV2",
    "pt4115": "jlc_parts:SOT-89-5_L4.5-W2.5-P1.50-LS4.5-BR",
    "mux":    "jlc_parts:SOIC-24_L15.4-W7.5-P1.27-LS10.3-BL",
    "button": "jlc_parts:SW-SMD_4P-L5.1-W5.1-P3.70-LS6.5-TL_H1.5",
    "r0603":  "Resistor_SMD:R_0603_1608Metric",
    "r0805":  "Resistor_SMD:R_0805_2012Metric",
    "c0603":  "Capacitor_SMD:C_0603_1608Metric",
    "c0805":  "Capacitor_SMD:C_0805_2012Metric",
    "led0805": "LED_SMD:LED_0805_2012Metric",
    "sma":    "Diode_SMD:D_SMA",
    "swpa4030": "Inductor_SMD:L_Sunlord_SWPA4030S",
    "swpa6045": "Inductor_SMD:L_Sunlord_SWPA6045S",
    "soic8":  "Package_SO:SOIC-8_3.9x4.9mm_P1.27mm",
    "tssop28": "Package_SO:TSSOP-28_4.4x9.7mm_P0.65mm",
    "vssop10": "Package_SO:TSSOP-10_3x3mm_P0.5mm",
    "sot23":  "Package_TO_SOT_SMD:SOT-23",
    "idc40":  "Connector_IDC:IDC-Header_2x20_P2.54mm_Vertical",
    "idc20":  "Connector_IDC:IDC-Header_2x10_P2.54mm_Horizontal",
    "sock19": "Connector_PinSocket_2.54mm:PinSocket_1x19_P2.54mm_Vertical",
    # KF301-5.0-2P (C474881): MX126 footprint geometry but drills enlarged to
    # 1.4 mm per JLCPCB/EasyEDA recommended pattern (KF301 blade pins are a
    # marginal fit in the stock MX126 1.3 mm holes).
    "screw2": "jlc_parts:TerminalBlock_KF301-5.0-2P_1x02_P5.00mm",
    "barrel": "Connector_BarrelJack:BarrelJack_Horizontal",
    "hdr2":   "Connector_PinHeader_2.54mm:PinHeader_1x02_P2.54mm_Vertical",
    "elec8":  "Capacitor_SMD:CP_Elec_8x10",
    "elec63": "Capacitor_SMD:CP_Elec_6.3x7.7",
    "hole":   "MountingHole:MountingHole_3.2mm_M3",
    "tp":     "TestPoint:TestPoint_Pad_1.5x1.5mm",
}

LIB = {
    "led":    "jlc_parts:HL-C3535F15R3GA-ZW",
    "pt4115": "jlc_parts:PT4115",
    "mux":    "jlc_parts:CD74HC4067M96",
    "button": "jlc_parts:TS-1187A-B-A-B",
    "r":      "Device:R",
    "c":      "Device:C",
    "cp":     "Device:C_Polarized",
    "l":      "Device:L",
    "dsch":   "Device:D_Schottky",
    "ntc":    "Device:Thermistor_NTC",
    "led2":   "Device:LED",
    "pca":    "Driver_LED:PCA9685PW",
    "xl1509": "Regulator_Switching:XL1509-5.0",
    "ads":    "Analog_ADC:ADS1115IDGS",
    "fet":    "Transistor_FET:AO3400A",
    "conn40": "Connector_Generic:Conn_02x20_Odd_Even",
    "conn20": "Connector_Generic:Conn_02x10_Odd_Even",
    "sock19": "Connector_Generic:Conn_01x19",
    "screw2": "Connector:Screw_Terminal_01x02",
    "barrel": "Connector:Barrel_Jack",
    "hdr2":   "Connector_Generic:Conn_01x02",
    "tp":     "Connector:TestPoint",
    "hole":   "Mechanical:MountingHole",
}


# ============================================================ LED BOARD

def build_led_board():
    parts, nets = [], {}

    def net(name, ref, pin):
        nets.setdefault(name, []).append((ref, str(pin)))

    # --- 96 LED/NTC clusters (indexed by grid well w; the logical channel
    #     carried on the ribbon is well_channel(w), possibly != w) ---
    for w in range(1, 97):
        r, c = ch_rc(w)
        # schematic cluster (A1): 55mm x-pitch, 55mm y-pitch
        sx, sy = 35 + (c - 1) * 55, 45 + (r - 1) * 55
        # pcb: 9mm grid, field origin (19.5, 14)
        px, py = 19.5 + (c - 1) * 9.0, 14.0 + (r - 1) * 9.0
        ch = well_channel(w)

        parts += [
            part(f"LED{w}", LIB["led"], "HL-C3535F15R3GA-ZW 660nm",
                 FP["led"], "C5445086", (sx, sy), (px, py), 0,
                 desc=f"660nm LED well{w} (row{r},col{c}) -> ch{ch}"),
            part(f"TH{w}", LIB["ntc"], "NTC 10k B3434",
                 FP["r0603"], "C13564", (sx + 17.78, sy - 5.08),
                 (px + 3.6, py - 2.0), 90,
                 desc=f"NTC under LED{w}"),
            part(f"R{w}", LIB["r"], "10k 1%",
                 FP["r0603"], "C25804", (sx + 17.78, sy + 8.89),
                 (px + 3.6, py + 2.0), 90,
                 desc=f"NTC divider lower leg well{w}"),
        ]
        ja, pa, pk = WELL_CONN[w]
        net(f"LED_A{ch}", f"LED{w}", 1)         # pad 1 = anode ('+' silk)
        net(f"LED_A{ch}", ja, pa)
        net(f"LED_K{ch}", f"LED{w}", 2)         # pad 2 = cathode
        net(f"LED_K{ch}", f"LED{w}", 3)         # pad 3 = thermal, tie to cathode
        net(f"LED_K{ch}", ja, pk)
        net("+3.3V", f"TH{w}", 1)
        net(f"NTC{w}", f"TH{w}", 2)
        net(f"NTC{w}", f"R{w}", 1)
        mref, mpin = ntc_mux(w)
        net(f"NTC{w}", mref, mpin)
        net("GND", f"R{w}", 2)

    # --- 6 muxes + decoupling (bottom strip) ---
    for m in range(1, 7):
        sx, sy = 60 + (m - 1) * 110, 520
        px, py = 24 + (m - 1) * 19, 88
        parts += [
            part(f"U{m}", LIB["mux"], "CD74HC4067M96", FP["mux"], "C496123",
                 (sx, sy), (px, py), 0, desc=f"NTC mux {m} (16 nearest wells)"),
            part(f"C{m}", LIB["c"], "100nF", FP["c0603"], "C14663",
                 (sx + 25.4, sy - 12.7), (px + 6.4, py - 7.0), 90,
                 desc=f"decoupling U{m}"),
        ]
        net("+3.3V", f"U{m}", 24)
        net("GND", f"U{m}", 12)
        net("GND", f"U{m}", 15)                 # /E enabled
        net(f"NTC_SIG{m}", f"U{m}", 1)          # COM
        for i, sig in ((10, "MUX_A0"), (11, "MUX_A1"), (14, "MUX_A2"),
                       (13, "MUX_A3")):
            net(sig, f"U{m}", i)
        net("+3.3V", f"C{m}", 1)
        net("GND", f"C{m}", 2)

    # --- connectors ---
    # J1..J6: 40-pin ribbons, 16 channels each; 3 top edge, 3 bottom
    for j in range(1, 7):
        sx, sy = 740, 40 + (j - 1) * 80
        px = 66 + ((j - 1) % 3) * 60
        py = 26.5 if j <= 3 else 135.3
        parts.append(part(f"J{j}", LIB["conn40"],
                          f"LED ribbon {j} (16 ch)",
                          FP["idc40"], "C9043", (sx, sy), (px, py), 90,
                          desc=f"2x20 IDC ribbon {j}"))
        for gp in (19, 35, 36, 37, 38, 39, 40):
            net("GND", f"J{j}", gp)
        # pin 20 left unconnected: IDE-cable key compatibility
    parts.append(part("J9", LIB["conn20"], "logic/analog", FP["idc20"],
                      "C9144", (740, 545), (7, 105), 90,
                      desc="2x10 IDC logic ribbon"))
    for p, sig in J5_PINOUT.items():
        net(sig, "J9", p)

    # --- test points ---
    for i, (tnet, txy) in enumerate([("+3.3V", (13, 86)), ("GND", (13, 90)),
                                     ("GND", (13, 94))], 1):
        parts.append(part(f"TP{i}", LIB["tp"], tnet, FP["tp"], "",
                          (0, 0), txy, 0, desc=f"test point {tnet}"))
        net(tnet, f"TP{i}", 1)

    # --- mounting holes: 4 corners of LED field + top mid ---
    holes = [(5.5, 5.5), (134.5, 5.5), (5.5, 82), (134.5, 82), (70, 5.5)]
    for i, (hx, hy) in enumerate(holes, 1):
        parts.append(part(f"H{i}", LIB["hole"], "M3", FP["hole"], "",
                          (0, 0), (hx, hy), 0, desc="M3 mounting hole"))

    board = dict(
        name="12x8 Led Array 9mm pitch",
        title="12x8 660nm LED Array - LED Board",
        paper="A1", size=(140, 120), layers=4,
        parts=parts, nets=nets)
    return board


# ======================================================== CONTROL BOARD

def build_control_board():
    parts, nets = [], {}

    def net(name, ref, pin):
        nets.setdefault(name, []).append((ref, str(pin)))

    # --- 96 driver channels (indexed by driver d; the logical channel it
    #     drives is drv_channel(d), possibly != d). DIM/SW stay per-driver. ---
    for d in range(1, 97):
        r, c = ch_rc(d)
        sx, sy = 45 + (c - 1) * 92, 50 + (r - 1) * 62   # A0 sheet
        px, py = 22 + (c - 1) * 12.0, 40 + (r - 1) * 14.0
        ch = drv_channel(d)

        parts += [
            part(f"U{d}", LIB["pt4115"], "PT4115", FP["pt4115"], "C347356",
                 (sx, sy), (px, py), 0, desc=f"buck CC driver {d} -> ch{ch}"),
            part(f"R{d}", LIB["r"], "0.39R 1%", FP["r0805"], "C2930218",
                 (sx - 20.32, sy - 7.62), (px - 3.8, py - 4.4), 90,
                 desc=f"Rsense drv{d} (256mA)"),
            part(f"L{d}", LIB["l"], "47uH", FP["swpa4030"], "C54731",
                 (sx + 16.51, sy - 7.62), (px + 3.2, py - 4.4), 0,
                 desc=f"buck inductor drv{d}"),
            part(f"D{d}", LIB["dsch"], "SS34", FP["sma"], "C8678",
                 (sx + 16.51, sy + 6.35), (px + 2.6, py + 4.2), 180,
                 desc=f"freewheel drv{d}"),
            part(f"C{d}", LIB["c"], "2.2uF 50V", FP["c0805"], "C125847",
                 (sx - 20.32, sy + 6.35), (px - 4.0, py + 4.2), 90,
                 desc=f"VIN cap drv{d}"),
            part(f"R{100 + d}", LIB["r"], "100k", FP["r0603"], "C25803",
                 (sx - 1.27, sy + 12.7), (px, py + 8.8), 0,
                 desc=f"DIM pulldown drv{d}"),
        ]
        # nets
        net("+24V", f"R{d}", 1)
        net("+24V", f"C{d}", 1)
        net("+24V", f"D{d}", 1)                 # cathode to +24V
        net("+24V", f"U{d}", 5)                 # VIN
        net(f"LED_A{ch}", f"R{d}", 2)           # CSN node
        net(f"LED_A{ch}", f"U{d}", 4)
        net(f"SW{d}", f"U{d}", 1)
        net(f"SW{d}", f"L{d}", 1)
        net(f"SW{d}", f"D{d}", 2)               # anode to SW
        net(f"LED_K{ch}", f"L{d}", 2)
        net(f"DIM{d}", f"U{d}", 3)
        net(f"DIM{d}", f"R{100 + d}", 1)
        net("GND", f"U{d}", 2)
        net("GND", f"C{d}", 2)
        net("GND", f"R{100 + d}", 2)
        ja, pa, pk = DRV_CONN[d]
        net(f"LED_A{ch}", ja, pa)
        net(f"LED_K{ch}", ja, pk)
        pca_ref, pca_pin = PCA_MAP[d]
        net(f"DIM{d}", pca_ref, pca_pin)

    # --- PCA9685 bank ---
    for k in range(6):
        u = f"U{101 + k}"
        sx, sy = 50 + k * 80, 600
        px, py = 30 + k * 20, 152
        parts += [
            part(u, LIB["pca"], f"PCA9685PW (0x{0x40 + k:02X})", FP["tssop28"],
                 "C2678753", (sx, sy), (px, py), 0,
                 desc=f"16ch PWM 0x{0x40 + k:02X} (drives its nearest driver cluster)"),
            part(f"C{121 + k}", LIB["c"], "100nF", FP["c0603"], "C14663",
                 (sx + 20.32, sy - 17.78), (px + 6.6, py - 3.0), 90,
                 desc=f"decoupling {u}"),
        ]
        net("+3.3V", u, PCA_PINS["VDD"])
        net("GND", u, PCA_PINS["GND"])
        net("GND", u, PCA_PINS["OE"])           # outputs live at reset (LOW)
        net("GND", u, PCA_PINS["EXTCLK"])       # unused, tie low
        net("I2C_SDA", u, PCA_PINS["SDA"])
        net("I2C_SCL", u, PCA_PINS["SCL"])
        # address straps: 0x40+k -> A5..A0 = k in binary (A6 fixed 1 internally)
        for bit, pname in enumerate(["A0", "A1", "A2", "A3", "A4", "A5"]):
            net("+3.3V" if (k >> bit) & 1 else "GND", u, PCA_PINS[pname])
        net("+3.3V", f"C{121 + k}", 1)
        net("GND", f"C{121 + k}", 2)

    # --- 5V rail: XL1509-5.0E1 buck ---
    #   XL1509 SOP8: extract pin names from symbol; expected LM2596-style:
    #   VIN, GND, /ON-OFF, FB, OUT
    sx, sy = 560, 700
    parts += [
        part("U110", LIB["xl1509"], "XL1509-5.0E1", FP["soic8"], "C61063",
             (sx, sy), (36, 172), 0, desc="24V->5V 2A buck"),
        part("C110", LIB["cp"], "100uF 50V", FP["elec8"], "C134514",
             (sx - 30.48, sy), (22, 172), 0, desc="5V buck input cap"),
        part("L101", LIB["l"], "47uH 2A+", FP["swpa6045"], "C36414",
             (sx + 25.4, sy - 5.08), (48, 168), 0, desc="5V buck inductor"),
        part("D101", LIB["dsch"], "SS34", FP["sma"], "C8678",
             (sx + 25.4, sy + 7.62), (48, 176), 90, desc="5V buck freewheel"),
        part("C111", LIB["cp"], "220uF 16V", FP["elec63"], "C286136",
             (sx + 45.72, sy), (58, 172), 0, desc="5V rail output cap"),
    ]
    # XL1509-5.0 (verified): 1=VIN 2=OUT 3=FB 4=/EN 5..8=GND
    net("+24V", "U110", 1); net("+24V", "C110", 1)
    net("GND", "C110", 2)
    net("SW_5V", "U110", 2)                             # OUT
    net("SW_5V", "L101", 1)
    net("SW_5V", "D101", 1)             # freewheel cathode to SW node
    net("GND", "D101", 2)               # anode to GND
    net("+5V", "L101", 2)
    net("+5V", "C111", 1)
    net("GND", "C111", 2)
    net("+5V", "U110", 3)                               # FB senses 5V rail
    net("GND", "U110", 4)                               # /EN low = enabled
    for gp in (5, 6, 7, 8):
        net("GND", "U110", gp)

    # --- bulk 24V caps ---
    for i in range(4):
        parts.append(part(f"C{101 + i}", LIB["cp"], "220uF 35V", FP["elec8"],
                          "C134820", (660 + i * 30.48, 700), (22 + i * 11, 183),
                          0, desc="24V bulk"))
        net("+24V", f"C{101 + i}", 1)
        net("GND", f"C{101 + i}", 2)

    # --- power inputs ---
    parts += [
        part("J12", LIB["screw2"], "24V IN", FP["screw2"], "C474881",
             (800, 700), (8, 172), 90, desc="24V screw terminal"),
        part("J7", LIB["barrel"], "24V IN (5.5/2.5)", FP["barrel"], "C381115",
             (800, 740), (8, 150), 0, desc="24V barrel jack 5A"),
    ]
    net("+24V", "J12", 1); net("GND", "J12", 2)
    net("+24V", "J7", 1); net("GND", "J7", 2)

    # --- fan output ---
    parts += [
        part("J8", LIB["hdr2"], "FAN 24V", FP["hdr2"], "C2337", (900, 700),
             (160, 183), 0, desc="fan header"),
        part("Q1", LIB["fet"], "AO3400A", FP["sot23"], "C20917", (900, 730),
             (160, 172), 0, desc="fan low-side switch"),
        part("R201", LIB["r"], "100R", FP["r0603"], "C22775", (880, 745),
             (155, 168), 90, desc="fan gate series"),
        part("R202", LIB["r"], "100k", FP["r0603"], "C25803", (920, 745),
             (165, 168), 90, desc="fan gate pulldown"),
        part("D102", LIB["dsch"], "SS34", FP["sma"], "C8678", (900, 680),
             (160, 177), 0, desc="fan flyback"),
    ]
    net("+24V", "J8", 1)
    net("FAN_SW", "J8", 2)
    net("FAN_SW", "Q1", 3)              # drain (AO3400A: 1=G 2=S 3=D verified at gen)
    net("FAN_SW", "D102", 2)
    net("+24V", "D102", 1)
    net("GND", "Q1", 2)
    net("FAN_G", "Q1", 1)
    net("FAN_G", "R201", 2)
    net("FAN_PWM", "R201", 1)
    net("FAN_G", "R202", 1)
    net("GND", "R202", 2)

    # --- ESP32 DevKitC socket ---
    parts += [
        part("J10", LIB["sock19"], "ESP32 left (3V3 row)", FP["sock19"],
             "C319202", (1000, 100), (140.0, 130), 0, desc="DevKitC-38 socket L"),
        part("J11", LIB["sock19"], "ESP32 right (GND row)", FP["sock19"],
             "C319202", (1030, 100), (165.4, 130), 0, desc="DevKitC-38 socket R"),
    ]
    for i, name in enumerate(ESP32_J10, 1):
        sig = {"3V3": "+3.3V", "5V": "+5V", "GND": "GND",
               "GPIO36/VP": "NTC_SIG5", "GPIO39/VN": "NTC_SIG6",
               "GPIO34": "NTC_SIG3", "GPIO35": "NTC_SIG4",
               "GPIO32": "NTC_SIG1", "GPIO33": "NTC_SIG2",
               "GPIO25": "FAN_PWM", "GPIO26": "BTN_DOWN", "GPIO27": "BTN_UP",
               "GPIO14": "BTN_MODE", "GPIO13": "LED_FAULT",
               }.get(name)
        if sig:
            net(sig, "J10", i)
    for i, name in enumerate(ESP32_J11, 1):
        sig = {"GND": "GND", "GPIO22": "I2C_SCL", "GPIO21": "I2C_SDA",
               "GPIO19": "MUX_A3", "GPIO18": "MUX_A2", "GPIO17": "MUX_A1",
               "GPIO16": "MUX_A0", "GPIO4": "LED_STATUS",
               }.get(name)
        if sig:
            net(sig, "J11", i)

    # --- I2C pullups ---
    parts += [
        part("R210", LIB["r"], "4.7k", FP["r0603"], "C23162", (1070, 600),
             (150, 145), 0, desc="SDA pullup"),
        part("R211", LIB["r"], "4.7k", FP["r0603"], "C23162", (1070, 615),
             (150, 148), 0, desc="SCL pullup"),
    ]
    net("I2C_SDA", "R210", 1); net("+3.3V", "R210", 2)
    net("I2C_SCL", "R211", 1); net("+3.3V", "R211", 2)

    # --- UI: buttons + status LEDs ---
    for i, (name, sig) in enumerate([("MODE", "BTN_MODE"), ("UP", "BTN_UP"),
                                     ("DOWN", "BTN_DOWN")], 1):
        parts.append(part(f"SW{i}", LIB["button"], name, FP["button"],
                          "C318884", (950 + (i - 1) * 40, 600),
                          (120 + (i - 1) * 12, 172), 0, desc=f"button {name}"))
        # TS-1187A: pins 1/2 one side, 3/4 other; 1-2 and 3-4 are pairs
        net(sig, f"SW{i}", 1)
        net(sig, f"SW{i}", 2)
        net("GND", f"SW{i}", 3)
        net("GND", f"SW{i}", 4)
    leds = [("LED1", "PWR green", "+5V", "R203", "2.2k", "C4190"),
            ("LED2", "STATUS blue", "LED_STATUS", "R204", "1k", "C21190"),
            ("LED3", "FAULT red", "LED_FAULT", "R205", "1k", "C21190")]
    for i, (lref, val, drive, rref, rval, rlcsc) in enumerate(leds):
        parts += [
            part(lref, LIB["led2"], val, FP["led0805"],
                 {"LED1": "C2297", "LED2": "C2293", "LED3": "C84256"}[lref],
                 (950 + i * 40, 640), (120 + i * 12, 162), 0, desc=val),
            part(rref, LIB["r"], rval, FP["r0603"], rlcsc,
                 (950 + i * 40, 660), (120 + i * 12, 158), 90,
                 desc=f"{lref} series R"),
        ]
        net(drive, rref, 1)
        net(f"{lref}_A", rref, 2)       # series R feeds LED anode
        net(f"{lref}_A", lref, 2)       # Device:LED pin2 = A
        net("GND", lref, 1)             # pin1 = K to GND

    # --- optional ADS1115 (DNP) ---
    parts.append(part("U111", LIB["ads"], "ADS1115IDGS (DNP)", FP["vssop10"],
                      "C37593", (1120, 600), (150, 155), 0, dnp=True,
                      desc="optional precision ADC"))
    net("+3.3V", "U111", 8); net("GND", "U111", 3)
    net("I2C_SDA", "U111", 10); net("I2C_SCL", "U111", 9)
    net("GND", "U111", 1)               # ADDR -> 0x48
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

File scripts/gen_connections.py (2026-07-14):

"""Generate CONNECTIONS.md - the complete hand-wiring guide.

Derived from design_data.py (same source as the schematics), with pin names
pulled from the actual symbol libraries via gen_schematics.extract_symbol.

Run:  python gen_connections.py
"""
import sys
from pathlib import Path

sys.path.insert(0, str(Path(__file__).resolve().parent))
import design_data as dd
import gen_schematics as gs

ROOT = Path(__file__).resolve().parent.parent
OUT = ROOT / "CONNECTIONS.md"


def pin_names(board):
    """ref -> {pin: name} using the real symbols."""
    cache, out = {}, {}
    for p in board["parts"]:
        if not p["lib_id"]:
            continue
        if p["lib_id"] not in cache:
            _, pins = gs.extract_symbol(p["lib_id"])
            cache[p["lib_id"]] = pins
        out[p["ref"]] = cache[p["lib_id"]]
    return out


def fmt_member(ref, pin, names):
    nm = names.get(ref, {}).get(pin, "")
    return f"{ref}.{pin}" + (f" ({nm})" if nm and nm != pin else "")


def net_line(board, names, netname):
    members = board["nets"].get(netname, [])
    return ", ".join(fmt_member(r, p, names) for r, p in members)


def main():
    led = dd.build_led_board()
    ctl = dd.build_control_board()
    lnames = pin_names(led)
    cnames = pin_names(ctl)

    L = []
    A = L.append
    A("# CONNECTIONS.md — complete wiring reference")
    A("")
    A("Generated from `scripts/design_data.py`. The hierarchical schematics "
      "are **already wired to match this document** (verified: KiCad's "
      "exported netlist matches every net below exactly, ERC clean). Use "
      "this as the review checklist and as the reference during PCB "
      "routing, firmware bring-up, and debugging.")
    A("")
    A("**Channel numbering:** `n = (row-1)*12 + col`, rows top→bottom 1-8, "
      "columns left→right 1-12 looking at the LED side. CH1 = top-left well, "
      "CH96 = bottom-right.")
    A("")

    # ---------------- ESP32 ----------------
    A("## ESP32 DevKitC-38 socket map (control board J10/J11)")
    A("")
    A("J10 = left socket row, J11 = right socket row, **pin 1 of both = the "
      "3V3/GND end** (opposite the USB connector).")
    A("")
    A("| J10 pin | DevKit pin | Connect to | | J11 pin | DevKit pin | Connect to |")
    A("|---|---|---|---|---|---|---|")
    j10n = {p: n for n, p in
            [(x, i) for i, x in enumerate(dd.ESP32_J10, 1)]}
    con10, con11 = {}, {}
    for netname, members in ctl["nets"].items():
        for ref, pin in members:
            if ref == "J10":
                con10[int(pin)] = netname
            if ref == "J11":
                con11[int(pin)] = netname
    for i in range(1, 20):
        A(f"| {i} | {dd.ESP32_J10[i-1]} | {con10.get(i, '—')} | "
          f"| {i} | {dd.ESP32_J11[i-1]} | {con11.get(i, '—')} |")
    A("")
    A("GPIO summary: " + "; ".join(f"**{k}** = {v}"
                                   for k, v in dd.GPIO_PLAN.items()))
    A("")

    # ---------------- logical channel map (firmware bible) ----------------
    A("## Logical channel map (well ↔ channel ↔ driver ↔ PWM)")
    A("")
    A("The driver serving a well is **not** the same index — each board's "
      "ribbon pinout was optimized independently to minimize crossings, and "
      "the cable wires them together slot-for-slot. Firmware addresses a "
      "well's brightness through the PCA output in this table, and reads its "
      "temperature through the mux input. **This is the mapping to hard-code.**")
    A("")
    well_of = {dd.well_channel(w): w for w in range(1, 97)}
    drv_of = {dd.drv_channel(d): d for d in range(1, 97)}
    A("| CH | Well (grid) | Ribbon | Driver | PWM (PCA.out) | NTC (mux.in) |")
    A("|---|---|---|---|---|---|")
    inv_led = {v: k for k, v in dd.PCA_LED_PIN.items()}
    for ch in range(1, 97):
        w = well_of[ch]; d = drv_of[ch]
        r, c = dd.ch_rc(w)
        ja, pa, pk = dd.WELL_CONN[w]
        pref, ppin = dd.PCA_MAP[d]
        mref, mpin = dd.ntc_mux(w)
        mch = 9 - mpin if mpin <= 9 else 31 - mpin
        A(f"| {ch} | LED{w} (r{r}c{c}) | {ja} p{pa}/{pk} | U{d} "
          f"| {pref}.LED{inv_led.get(ppin,'?')} | {mref}.I{mch} |")
    A("")

    # ---------------- control board channel ----------------
    A("## Control board — driver channel (repeat for n = 1…96)")
    A("")
    A("```")
    A("+24V ──┬── R<n>.1   R<n> = 0.39Ω sense")
    A("       │   R<n>.2 ──●── U<n>.4 (CSN) ── LED_A<n> ── ribbon pin (see table)")
    A("       ├── C<n>.1   (2.2µF 50V; C<n>.2 → GND)")
    A("       ├── D<n>.1   (SS34 cathode/band side!)")
    A("       └── U<n>.5 (VIN)")
    A("U<n>.1 (SW) ──●── L<n>.1        L<n> = 47µH")
    A("              └── D<n>.2 (SS34 anode)")
    A("L<n>.2 ── LED_K<n> ── ribbon pin (see table)")
    A("U<n>.3 (DIM) ──●── R<10x>.1 (100k pulldown; .2 → GND)")
    A("               └── PCA9685 output (see table)")
    A("U<n>.2 (GND) → GND")
    A("```")
    A("")
    A("Drivers are indexed physically (U1…U96); the logical channel each "
      "carries is CH = whichever ribbon slot it was assigned. Table sorted "
      "by driver.")
    A("")
    A("| Driver | CH | Rs | L | D | Cin | pulldown | ribbon A / K | DIM source |")
    A("|---|---|---|---|---|---|---|---|---|")
    inv_pca_led = {v: k for k, v in dd.PCA_LED_PIN.items()}
    for d in range(1, 97):
        ch = dd.drv_channel(d)
        ja, pa, pk = dd.DRV_CONN[d]
        pref, ppin = dd.PCA_MAP[d]
        li = inv_pca_led.get(ppin, "?")
        A(f"| U{d} | {ch} | R{d} | L{d} | D{d} | C{d} | R{100+d} "
          f"| {ja}.{pa} / {ja}.{pk} | {pref}.{ppin} (LED{li}) |")
    A("")

    # ---------------- PCA9685 ----------------
    A("## PCA9685 bank (control board)")
    A("")
    A("All six: pin 28 (VDD) → +3.3V with 100nF (C121-C126), pin 14 (VSS) → "
      "GND, pin 23 (/OE) → GND, pin 25 (EXTCLK) → GND, pin 27 (SDA) → "
      "I2C_SDA, pin 26 (SCL) → I2C_SCL.")
    A("I2C_SDA/I2C_SCL → ESP32 GPIO21/GPIO22 + 4.7k pullups R210/R211 to +3.3V.")
    A("")
    A("Address straps (pin → rail):")
    A("")
    A("| Chip | Addr | A0(1) | A1(2) | A2(3) | A3(4) | A4(5) | A5(24) |")
    A("|---|---|---|---|---|---|---|---|")
    for k in range(6):
        bits = ["+3.3V" if (k >> b) & 1 else "GND" for b in range(6)]
        A(f"| U{101+k} | 0x{0x40+k:02X} | " + " | ".join(bits) + " |")
    A("")

    # ---------------- power / fan / UI ----------------
    for title, nets_ in [
        ("5V rail (control board)",
         ["+24V", "SW_5V", "+5V"]),
        ("Fan output (control board)",
         ["FAN_PWM", "FAN_G", "FAN_SW"]),
        ("UI buttons + status LEDs (control board)",
         ["BTN_MODE", "BTN_UP", "BTN_DOWN", "LED_STATUS", "LED_FAULT",
          "LED1_A", "LED2_A", "LED3_A"]),
        ("I2C (control board)", ["I2C_SDA", "I2C_SCL"]),
    ]:
        A(f"## {title}")
        A("")
        for nn in nets_:
            if nn in ctl["nets"]:
                A(f"- **{nn}**: {net_line(ctl, cnames, nn)}")
        A("")
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

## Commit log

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2026-07-13 Generate both schematics: all parts placed with verified pinouts
    - 310 parts LED board (96 LED/NTC/R clusters, 6 muxes, 5 IDC)
    - 627 parts control board (96 PT4115 channels, 6 PCA9685, 5V rail,
    ESP32 socket, UI buttons/LEDs, fan driver)
    - design_data.py is the single source of truth incl. full netlist
    - pin numbers cross-validated against KiCad + EasyEDA symbol libraries
    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
    [12x8 Led Array 9mm pitch.kicad_sch, control-board.kicad_sch]
2026-07-13 Add CONNECTIONS.md wiring guide, README, schematic PDFs, draft PCBs
    - CONNECTIONS.md generated from design_data with library-verified pin
    names; cross-board ribbon consistency asserted
    - Draft .kicad_pcb files exist but are ON HOLD (placement overlaps)
    pending schematic verification
    - README with design rules, LED wavelength swap guide, GPIO map
    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
    [12x8 Led Array 9mm pitch.kicad_pcb, control-board.kicad_pcb]
2026-07-13 Hierarchical schematics: fully wired, netlist-verified, ERC clean
    - Root + well.kicad_sch / channel.kicad_sch instantiated 96x each;
    refs preserved (LED1-96, U1-96...) via instance paths
    - Sub-sheets pre-wired; root connected via net labels; no_connects
    on unused ESP32 socket pins; PWR_FLAGs per rail
    - verify_netlist.py: KiCad netlist export matches design_data on all
    300 (LED) + 412 (control) intended nets; ERC clean / 3 benign warns
    - LCSC corrections from verification agent applied (C125847, C134514,
    C286136, C134820, C36414); datasheets for all parts in reference/
    - jlc_parts pins normalized to passive
    Claude-Session: https: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
    [12x8 Led Array 9mm pitch.kicad_sch, channel.kicad_sch, control-board.kicad_sch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]
2026-07-13 Add test points and mounting holes to schematics
    - LED board: TP1-TP3 (+3V3, GND x2); H1-H5 as Mechanical:MountingHole
    - Control board: TP1-TP12 (rails, SW_5V, I2C, FAN_SW, CH1 debug set
    DIM1/LED_A1/LED_K1); H1-H4
    - 1.5mm bare-pad TestPoint footprints (no BOM cost)
    - Netlist re-verified: all nets match; ERC still clean
    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
    [12x8 Led Array 9mm pitch.kicad_sch, control-board.kicad_pcb, control-board.kicad_sch]
2026-07-13 Footprint audit: KF301 terminal footprint with 1.4mm drills
    Agent audit verified every footprint pad-for-pad against JLCPCB/EasyEDA
    package data; only fix needed was the KF301-5.0-2P screw terminal
    (stock MX126 footprint has 1.3mm drills, JLC recommends 1.4mm for the
    KF301 blade pins). New footprint in libraries/jlc_parts.pretty;
    schematics regenerated; netlist verification still passes on all nets.
    Full audit report in reference/datasheets/PART_VERIFICATION.json.
    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
    [control-board.kicad_sch]
2026-07-13 3D models: all footprints resolved, KF301 + ESP32 DevKitC models added
    - jlc_parts model paths rewritten to ${KIPRJMOD}-relative (were bare
    relative, unresolvable from project dirs), incl. embedded PCB copies
    - Real KF301-5.0-2P model (EasyEDA C474881) attached w/ 2.5mm offset
    - ESP32-DevKitC-38 full-board STEP added; attach instructions in
    reference/3D_MODELS.md (full audit table there too)
    - 24/26 footprints have valid models; MountingHole + TestPoint are
    intentionally model-less
    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
    [12x8 Led Array 9mm pitch.kicad_pcb, 12x8 Led Array 9mm pitch.kicad_sch, control-board.kicad_pcb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]
2026-07-13 Apply user's label cleanup style to control board
    - All generated labels now carry explicit justification (left/right
    per rotation, bottom-anchored) matching the hand-cleaned LED board
    - gen_schematics_hier.py takes led|ctl|all arg; LED board excluded
    from regeneration by default (hand-edited in KiCad)
    - Control board netlist re-verified: all 412 nets match
    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
    [12x8 Led Array 9mm pitch.kicad_pcb, 12x8 Led Array 9mm pitch.kicad_sch, control-board.kicad_sch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]
2026-07-13 Fix 3.3V/GND bridge, adopt +3.3V naming, power symbols at rail pins
    - Removed 6 wire segments that tied each mux VCC run into its
    decoupling cap's GND pin (merged the rails through all six caps)
    - Renamed +3V3 -> +3.3V everywhere (user convention), incl. well
    sub-sheet power symbols and docs
    - Control board root now uses real power symbols on wire stubs
    instead of text labels for GND/+3.3V/+5V/+24V (user style)
    - Verified: netlists match design intent on all 300+412 nets; LED
    board ERC 0 violations; I2C addresses confirmed from netlist
    (PCA9685 0x40-0x45, ADS1115 0x48, no conflicts)
    Claude-Session: https://claude.ai/code/sessi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
    [12x8 Led Array 9mm pitch.kicad_sch, control-board.kicad_sch, well.kicad_sch]
2026-07-13 Optimize ribbon/mux pin assignments to match user's PCB placement
    - Quadrant mapping from actual footprint positions (via pcbnew API):
    J1 left-back = cols1-6/rows1-4, J2 right-back = cols7-12/rows1-4,
    J4 left-front = cols1-6/rows5-8, J3 right-front = cols7-12/rows5-8;
    pin pairs column-major in physical pin-1 direction (nested fan-out,
    no crossings)
    - NTC->mux side-matched: U1-U3 serve cols 1-6, U6/U5/U4 cols 7-12
    - pin_maps.py generated by optimize_pins.py; design_data now table-driven
    - 274 labels renamed in the hand-edited LED sch (proximity-matched,
    0 misses); control board regenerated; CONNECTIONS.md updated
    - Both netlists verify (300+412 nets), LED ERC still 0 errors
    Co-Auth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
    [12x8 Led Array 9mm pitch.kicad_pcb, 12x8 Led Array 9mm pitch.kicad_sch, control-board.kicad_sch]
2026-07-13 LED board outline + placement fixes for user's layout
    - Rounded-rect Edge.Cuts (195 x 131.8mm) fenced around actual
    footprint extents; old draft outline removed
    - Stray holes H2/H4/H5 relocated inside the new outline
    - Mux decoupling caps C1-C6 nudged 3.5mm outboard (pads overlapped
    mux pin rows - 6 shorts + 6 clearance violations resolved)
    - DRC now silk-cosmetics only
    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
    [12x8 Led Array 9mm pitch.kicad_pcb]
2026-07-13 Pull mux strips in (board now 190x131.8mm), thermal via farms + fills
    - U1-U3/C1-C3 +5mm, U4-U6/C4-C6 -5mm; outline redrawn; H4 -> (227,128)
    - 480 thermal vias (0.3/0.6mm, 5 per LED pad 3, cathode nets)
    - 96 B.Cu cathode islands (6.5mm, solid connect, priority 2) + GND
    planes on In1/In2/B.Cu resized to new outline and filled
    - PCB nets refreshed from the FIXED schematic netlist (board still
    carried the pre-fix merged +3.3V/GND net; GND net recreated,
    1051 pads re-netted, vias + zones re-assigned)
    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
    [12x8 Led Array 9mm pitch.kicad_pcb]
2026-07-13 Refill zones with connectivity (fixes scripted-fill DRC artifacts)
    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
    [12x8 Led Array 9mm pitch.kicad_pcb]
2026-07-13 JLCPCB production exports: BOM + CPL for both boards
    - BOM grouped by LCSC part (LED board 5 lines / control 29 lines)
    - CPL from actual PCB positions via pcbnew (JLC Y-up convention)
    - THT connectors + DNP + holes excluded (hand-solder plan)
    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
    [12x8 Led Array 9mm pitch.kicad_pcb, BOM_control-board.csv, BOM_led-board.csv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]
2026-07-13 Sandwich layout: J1/J2 ribbon headers moved to top edge
    - J1/J2 (rows 1-4 quadrants) now on top edge, J3/J4 single row on
    bottom - ribbons wrap opposite edges for the board sandwich
    - Halves corridor congestion (8 traces/column gap instead of 16);
    bottom connectors no longer stacked two-deep
    - Logical pin mapping unchanged (J1/J2 already owned rows 1-4):
    0 label renames, netlists still verify
    - Signal routing ripped for fresh autoroute; GND stitching + thermal
    via farms retained; outline redrawn (196 x 133.5mm); H1/H5 moved
    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
    [12x8 Led Array 9mm pitch.kicad_pcb]
2026-07-13 Condense LED board: muxes to back side, J5 beside J3 (189x139.9mm)
    - U1-U6 + decoupling flipped to B.Cu, tucked outside the LED field /
    heatsink zone (two-sided assembly; LED side reflows second)
    - J5 rotated horizontal below J3; holes repositioned via measured
    courtyards (IDC footprints are end-origin, not centered!)
    - Stale GND stubs cleaned + re-stitched; zones refilled
    - Placement DRC clean (cosmetic silk only)
    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
    [12x8 Led Array 9mm pitch.kicad_pcb]
2026-07-13 Mux split 4 left / 2 right, column-pair NTC mapping
    - U1-U4 left stack, U5/U6 right beside J5 (user layout request)
    - Each mux owns 2 columns; 94 NTC labels remapped; netlists verify
    - Old stubs swept, GND re-stitched, placement DRC clean
    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
    [12x8 Led Array 9mm pitch.kicad_pcb, 12x8 Led Array 9mm pitch.kicad_sch]
2026-07-14 15mm keep-out from array for all support parts; J5 joins right mux pair
    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
    [12x8 Led Array 9mm pitch.kicad_pcb]
2026-07-14 Symmetric aesthetic layout: equal 35mm margins, J5 centered between muxes
    - Board 173.7 x 137.7mm, array dead-center both axes
    - Left: cap/mux column mirrored by right cap/mux/J5/mux/cap column
    - 4 corner holes + bottom-center hole; TP row bottom-right
    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
    [12x8 Led Array 9mm pitch.kicad_pcb]
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2026-07-14 Control board arranged to mirror LED board (sandwich stack)
    - 218 x 137.7mm, same height + mounting-hole spacing (162.7x126.7)
    as LED board for shared standoffs
    - 96 driver cells 12x8, X-mirrored so ribbons run straight; 12x12mm
    cells (PT4115+L+D+Rs+Cin+pulldown, all front side)
    - Connectors mirrored: J2/J1 top, J3/J4 bottom, J5 left edge
    - Left: PCA stack U101-103; right: ESP32 sockets (USB up) + U104-106
    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
    [control-board.kicad_pcb]
2026-07-14 Control board refinement: headers rotated 180 (ribbon-fold correct, crossing-free fan-out), PCA stacks aligned to channel bands, right column shifted clear of connector shroud lips; placement DRC cle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
    [control-board.kicad_pcb]
2026-07-14 Control board fill/coupling pass: field rows spread to 12.25mm pitch, bulk caps split input/load side, XL group tight column, I2C parts at ESP32 SDA/SCL end, TP grid fills right-middle, fan header on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
    [control-board.kicad_pcb]
2026-07-14 Control board: bottom-half cells mirrored toward J3/J4, pulldowns in disjoint per-half columns, silk declutter (288 passive refs hidden, rest shrunk to 0.9mm); placement DRC clean
    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
    [control-board.kicad_pcb]
2026-07-14 LED board: fanout vias for all 138 back-side signal pads
    Root cause of stuck routing: mux/cap pads live on B.Cu which is
    locked as a plane layer for the autorouter - unreachable. Staggered
    via fanout (0.6/0.3, collision-checked) brings every back-side signal
    to the routable layers; B.Cu stays clean.
    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
    [12x8 Led Array 9mm pitch.kicad_pcb]
2026-07-14 Muxes and caps back to front side (single-sided assembly restored)
    The back-side move no longer bought any board size (15mm keep-out +
    J5 column set the width) while costing double-sided assembly and
    unroutable pads. Fanout removed, parts unflipped in place, GND
    re-stitched on front, placement DRC clean.
    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
    [12x8 Led Array 9mm pitch.kicad_pcb]
2026-07-14 LED board routed: 4600+ tracks via Freerouting after back-side fix
    97% complete - 15 connections left for manual routing (11 LED_K +
    LED_A83 near J2/J4 outer pin rows, 3 GND edge pins). Dangling scraps
    swept; zones filled.
    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
    [12x8 Led Array 9mm pitch.kicad_pcb]
2026-07-14 Control board upgraded to 4-layer: In1 GND plane, In2 +24V plane
    - Solid return plane under all 96 buck cells (EMI/return-path fix)
    - 856 power stitching vias (every GND/+24V SMD pad -> its plane)
    - Old 2-layer routing ripped; signals reroute on clean outer layers
    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
    [control-board.kicad_pcb]
2026-07-14 Swap to 6x 40-pin IDC ribbons (IDE-safe pinout), clear routing for rearrange
    - J1-J6 both boards: 16 channels each = one PCA9685 bank per cable;
    pairs on pins 1-18/21-34, pin 20 NC (IDE key), GND 19+35-40
    - Logic ribbon renamed J9; control screw terminal now J12
    - Schematics regenerated (netlists verified 300+412), CONNECTIONS
    updated; connectors placed at nominal spots for user rearrangement
    - All routing cleared except LED thermal via farms per user request
    - New vault note: What Every Part Does
    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
    [12x8 Led Array 9mm pitch.kicad_pcb, 12x8 Led Array 9mm pitch.kicad_sch, control-board.kicad_pcb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]
2026-07-14 Driver-board pinout optimization from user's rearranged placement
    - CONN_MAP: per-ribbon pair order jointly optimized against BOTH
    boards' geometry (pads projected on connector axes, combined rank)
    - PCA_MAP: each PCA9685's 16 outputs assigned to its bank's DIM
    lines by physical order (crossing-free fan-out)
    - design_data table-driven; schematics regenerated; netlists verify
    (300+412); pads re-netted on both boards; CONNECTIONS updated
    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
    [12x8 Led Array 9mm pitch.kicad_pcb, 12x8 Led Array 9mm pitch.kicad_sch, control-board.kicad_pcb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]
2026-07-14 LED board support parts copied to control-board topology (15mm border kept)
    J1/J4 vertical on left edge, J2/J3 top, J5/J6 bottom, mux stack +
    J9 on right strip; pin_maps v6 (CONN_MAP re-optimized, NTC_MAP
    re-derived for right-strip muxes); schematics regenerated, netlists
    verified, pads re-netted, zones refilled. New scripts:
    layout_led_support.py, apply_netlist.py.
    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
    [12x8 Led Array 9mm pitch.kicad_pcb, 12x8 Led Array 9mm pitch.kicad_sch, control-board.kicad_pcb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]
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2026-07-14 Decouple driver<->well mapping to slash ribbon crossings (461 -> 126/130)
    Key insight (user): the driver serving a well need not share its index.
    A ribbon SLOT (connector + IDE-safe pin-pair) is now the logical channel;
    wells and drivers are assigned to slots INDEPENDENTLY, each board optimized
    on its own geometry, cable wires slot-for-slot.
    optimize_decoupled.py: per board, balanced min-distance grouping (0 crossings
    BETWEEN ribbons) + angle order + 2-opt on the true anode/cathode-pad
    ratsnest. Real crossings: LED 461->126, control ->130 (short local A/K
    wires only; the board-spanning tangle is gone).
    design_data.py: nets keyed by logical channel via slot2ch(); wells indexed
    by grid (LED/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
    [12x8 Led Array 9mm pitch.kicad_pcb, 12x8 Led Array 9mm pitch.kicad_sch, control-board.kicad_pcb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]
2026-07-14 Add colored functional net classes to both boards
    7 classes with distinct colors + name-pattern auto-assignment (same on
    both boards): Power (red, 0.5mm), LED_Power (orange, 0.3mm), Switch
    (purple, 0.3mm), PWM (green, 0.2mm), Analog (cyan, 0.2mm), I2C (yellow,
    0.2mm), Default. Priority resolves SW_5V->Power vs SW#->Switch. Widths
    tuned for routing: fat power/LED, thin logic.
    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
